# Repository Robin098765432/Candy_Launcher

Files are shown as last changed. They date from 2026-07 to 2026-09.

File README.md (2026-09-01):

# Candy Launcher V1


Hi, this is a finished v1 of the candy launcher, currently only tested on my laptop (HP Victus). 



link to video with more details:
[https://www.youtube.com/watch?v=WshQ-3ue9KE](https://www.youtube.com/watch?v=Oau0cctOxF0)

## Why I Made It
I wanted to build a fun, automated way to launch candy using computer vision, combining hardware (an ESP32 and mechanical parts) with a custom software setup.

## Future updates will bring:
1. improved face tracking, one that also work in dim light
2. improved IK (there seems to be a bug that stops it from following to the full range)
3. improved shot consitency
4. other candy options

## Requirements

### Python

The python script was written with Python 3 and currently only tested on Windows.

Install the required python libraries:

```bash
pip install psutil requests opencv-python numpy
```

### OpenCV

OpenCV already includes:

- `haarcascade_frontalface_default.xml`

You still need to download:

- `haarcascade_mcs_mouth.xml`

and place it in the same folder as the python script.

### ESP32

This project uses an AI-Thinker ESP32-CAM.

Install the ESP32 by Espressif Systems board package through the Arduino IDE Boards Manager.

The following libraries are already included with the board package, so you don't have to install anything extra:

- WiFi
- esp_camera
- esp_http_server

The sketch also expects a `board_config.h` file for the camera pin definitions.

## How to Use It

1. Your laptop must have the physical OMEN Gaming Hub key on the keyboard.
2. Install Python and the required libraries shown above.
3. Download `haarcascade_mcs_mouth.xml` and put it next to the python script.
4. Install the ESP32 board package in the Arduino IDE.
5. Upload the ESP code to the AI-Thinker ESP32 board.
6. Change the Wi-Fi name and password in the ESP sketch.
7. Set the python script to run on Windows startup.
8. Press the OMEN key to enter livestream mode where the python script shows a box around your mouth.

> **Note:** Other esp code is purely for debugging hardware, if something is not working, test the respective section with that code

## CAD
* **CAD Model:** You can check out the design here: [Onshape CAD Document](https://cad.onshape.com/documents/5612db996652adceb7ce30aa/w/0ed39498cd0338a43115c5e1/e/3f8492fab05c535707b619d7)

## Assembly and explanation

> Assembly steps are not set in stone and there are multiple ways to Rome, this is just how i did it. :)
1. mill the pcb out of 1.6mm copper clad, 3d print all the files in the stl folder(make sure the tube and flywheels are printed in tpu)(also make sure that the lid and container are paused at the correct layer and insert the magnets)
2. insert heated inserts in all the holes in the base and solder all components to the pcb
3. mount the servos horns and servos as shown in the picture and bolt them in place


>the 3 servos will be used in sync to tilt the platform towards your mouth
4. insert the balljoints in the circular cutout in the pushrods(should be a press fit), and interlock the side with the fingers with the pushrods with the servo horns and put a bolt through.
> should be a low friction fit

5. mount the pcb with washers as spacers to the platform as shown below. also mount the slide(needs heated inserts first), also mount the motor and the flywheel(all pressfits but can use some glue)


6. install some heated inserts in the container, and mount the cap, slider, servo and servo gear(servo with hot glue), also mount the small dc motor with hot glue in the recess in the cap. and screw the printed weight on the motor shaft


> make sure the servo gear is not installed when first turned on because the servo might jerk to 0 on power on.
> 
> the servo and motor work together to shake the skittles and feed them one at a time
7. connect all the wires according to the diagram
8. snap the tube into the cap and the slide to connect the 2 assemblies and mount on a wall with screws.


9. DONE!!

## Wiring
Candy launcer wiring diagram

## BOM

> Prices are in USD converted from EUR, so they might not be 100% accurate, especially with American websites.

| Item | Qty | Price (USD from EUR, might not be accurate with American websites) | Description | Source / Link |
| :--- | :--- | ---: | :--- | :--- |
| Microcontroller | 1 | 11.55 | AI-Thinker ESP32-CAM | [Link](https://www.amazon.nl/dp/B0D46FHMKQ?ref=ppx_yo2ov_dt_b_fed_asin_title) |
| Host Computer | 1 | 1848.36 | HP Victus Laptop (with OMEN Gaming Hub key) | Owner's Hardware |
| USB Programming Cable | 1 | 10.39 | USB-to-Type-C cable | [Link](https://www.amazon.nl/SUNGUY-USB-compatibel-Android-Auto/dp/B0B28ZCV2Y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) |
| Pcb board | 1, if youre sure you wont mess the milling up;) | 19.36 | single sided | [Link](https://www.amazon.nl/gp/product/B015PCKPXE/ref=ewc_pr_img_1?smid=AQ1IBDB6G2RRD&psc=1) |
| Connecting Wires | as much as you need, can also use some wires you pull out of broken household machines | 0-22.53 | some wires | [Link](https://www.amazon.nl/vaste-gecoat-kleuren-vertind-Fermerry/dp/B09BFFGTLH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) |
| Pla and Tpu  | a roll each | about 44 | for the prints | any online store  |
| power supply | 1 | 18.5 | 5v 6A | [Link](https://www.amazon.nl/dp/B07P8HKFLL?ref=ppx_yo2ov_dt_b_fed_asin_title&th=1) |
| servo | 3 | 25.43 | 15kg | [Link](https://www.amazon.nl/dp/B0DHD4J3B4?ref=ppx_yo2ov_dt_b_fed_asin_title&th=1) |
| bolts  | quite a few | 10.4 | m3 | [Link](https://www.amazon.nl/dp/B0DQ17WWGQ?ref=ppx_yo2ov_dt_b_fed_asin_title&th=1) |
| heated inserts | quite a few | 7.51 | m3 | [Link](https://www.amazon.nl/dp/B0CH32W3W5?ref=ppx_yo2ov_dt_b_fed_asin_title) |
| skittles | depents how much you like skittles | 2.76/pack(150g) | you got to have something to fire | Local store |
| mosfed | 1 | 3.83 | IRL3103 | [Link](https://nl.aliexpress.com/item/1005007481357436.html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) |
| Capacitor | 1 | 3 | 1000uf, >16v | [Link](https://nl.aliexpress.com/item/1005012180336454.html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) |
| magnets, optional | 12 | 5 | 2mm by 4 mm | [Link](https://nl.aliexpress.com/item/1005012419891895.html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) |
| cheap dc motor 5v | 2 | 6 | for shaking and launching | [Link](https://www.amazon.nl/JZK-mini-motor-micro-elektrische-doe-het-zelf-afstandsbediening/dp/B09TRFBSFV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) |
| 9g servo | 1 | 10 | not a lot of torque is needed | [Link](https://www.amazon.nl/Servomotor-Accessoires-Prestatie-Helikopters-Vliegtuigen/dp/B0GXZNC7WV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) |
| rc ball joints  | 3 | 9 | for the platform | [Link](https://www.amazon.nl/dp/B097H25M92?ref=ppx_yo2ov_dt_b_fed_asin_title) |
| resistor 10k ohm | 1 | 0.15 | for the mosfed | [Link](https://www.bitsandparts.nl/weerstand-10k-ohm-1-4w-5pct-p101270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) |
| headers | quite a few |  | to plug everything in | [Link](https://www.amazon.nl/Glarks-Mannelijke-Vrouwelijke-Assortiment-Stapelbare/dp/B09BDX69VX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) |

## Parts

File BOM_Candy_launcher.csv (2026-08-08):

Item | Qty | price(USD from eur, might not be accurate with american websites) | Description | Source / Link
Microcontroller | 1 | 11.55 | AI-Thinker ESP32-CAM | https://www.amazon.nl/dp/B0D46FHMKQ?ref=ppx_yo2ov_dt_b_fed_asin_title
Host Computer | 1 | 1848.36 | HP Victus Laptop (with OMEN Gaming Hub key) | Owner's Hardware
USB Programming Cable | 1 | 10.39 | USB-to-Type-C cable | https://www.amazon.nl/SUNGUY-USB-compatibel-Android-Auto/dp/B0B28ZCV2Y?mcid=637835adbbfa3ec5b925935d5940d08b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
Pcb board | 1, if youre sure you wont mess the milling up;) | 19.36 | single sided | https://www.amazon.nl/gp/product/B015PCKPXE/ref=ewc_pr_img_1?smid=AQ1IBDB6G2RRD&psc=1
Connecting Wires | as much as you need, can also use some wires you pull out of broken household machines | 0-22.53 | some wires | https://www.amazon.nl/vaste-gecoat-kleuren-vertind-Fermerry/dp/B09BFFGTLH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
Pla and Tpu | a roll each | about 44 | for the prints | any online store
drone motor | 2 | 1.13 | for the firing mechanism | https://www.aliexpress.com/p/tesla-landing/index.html?scenario=c_ppc_item_bridge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
power supply | 1 | 18.5 | 5v 6A | https://www.amazon.nl/dp/B07P8HKFLL?ref=ppx_yo2ov_dt_b_fed_asin_title&th=1
servo | 3 | 25.43 | 15kg | https://www.amazon.nl/dp/B0DHD4J3B4?ref=ppx_yo2ov_dt_b_fed_asin_title&th=1
bolts | quite a few | 10.4 | m3 | https://www.amazon.nl/dp/B0DQ17WWGQ?ref=ppx_yo2ov_dt_b_fed_asin_title&th=1
heated inserts | quite a few | 7.51 | m3 | https://www.amazon.nl/dp/B0CH32W3W5?ref=ppx_yo2ov_dt_b_fed_asin_title
skittles | depents how much you like skittles | 2.76/pack(150g) | you got to have something to fire | Local store
mosfed | 1 | 3.83 | IRL3103 | https://nl.aliexpress.com/item/1005007481357436.html
nail | 6 | 5 | 2mm round dia | Local store
magnets, optional | 12 | 5 | 2mm by 4 mm | https://nl.aliexpress.com/item/1005012419891895.html?curPageLogUid=4vGJzhw6EWXI
cheap dc motor 5v | 1 | about 2 | any small one will do | Local store
9g servo | 1 | 10 | not a lot of torque is needed | https://www.amazon.nl/Servomotor-Accessoires-Prestatie-Helikopters-Vliegtuigen/dp/B0GXZNC7WV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

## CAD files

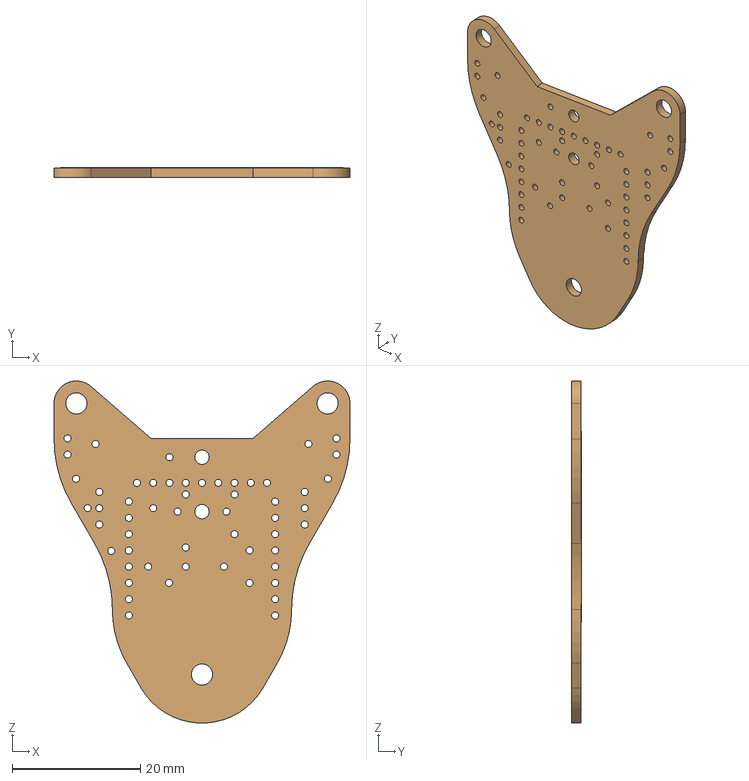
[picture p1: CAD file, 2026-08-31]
Candy launcher - PCB.step
46.2 x 1.60 x 53.4 mm

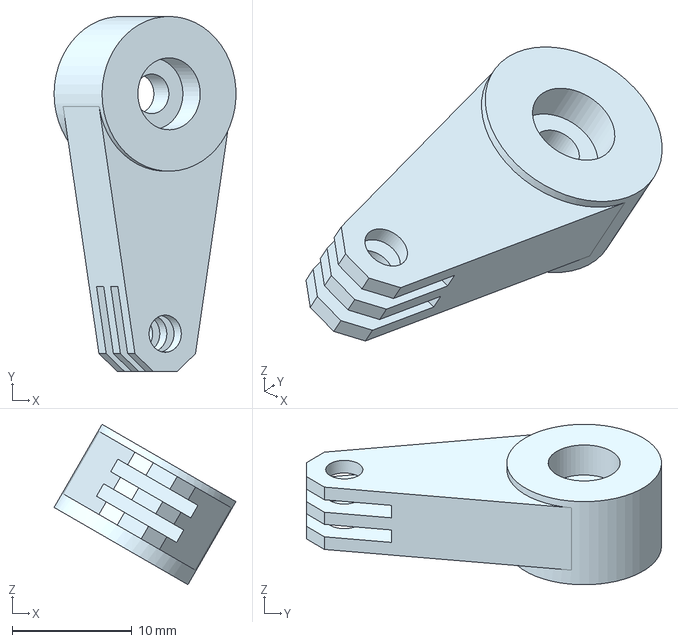
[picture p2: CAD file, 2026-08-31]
Candy launcher step files/Candy launcher - Servo Horn 1.step
15.2 x 29.6 x 13.4 mm

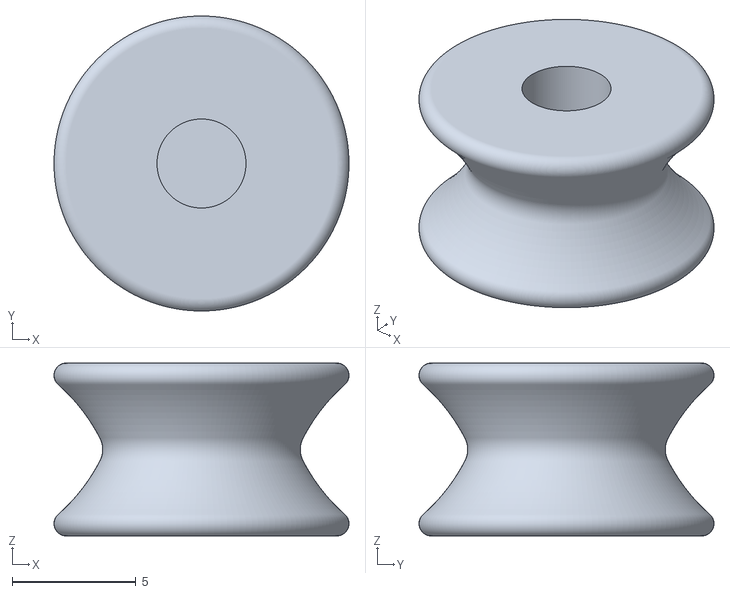
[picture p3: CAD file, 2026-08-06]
Candy launcher Stl files/Candy launcher - Flywheel 2.stl
11.9 x 11.9 x 7.00

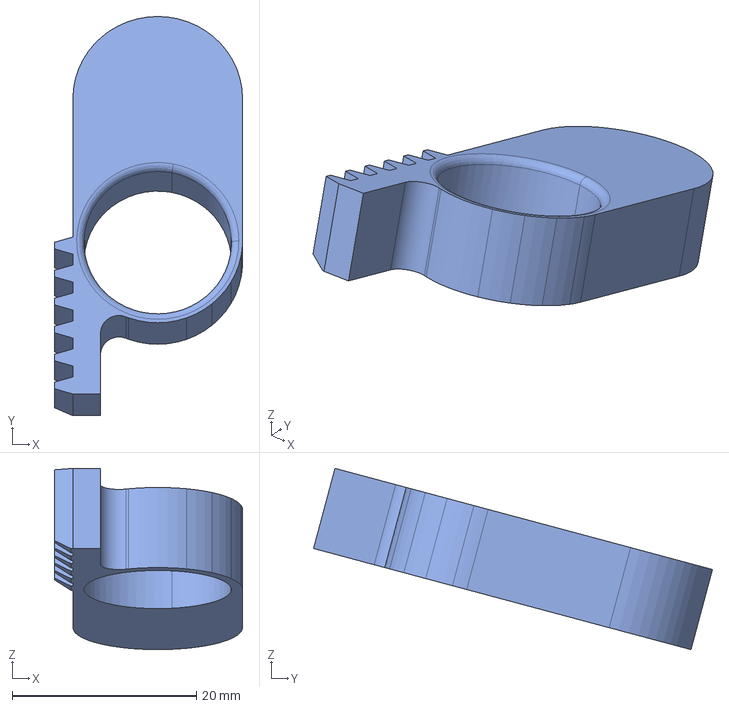
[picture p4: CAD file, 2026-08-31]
Candy launcher step files/Candy launcher - Slider.step
20.4 x 43.3 x 19.7 mm

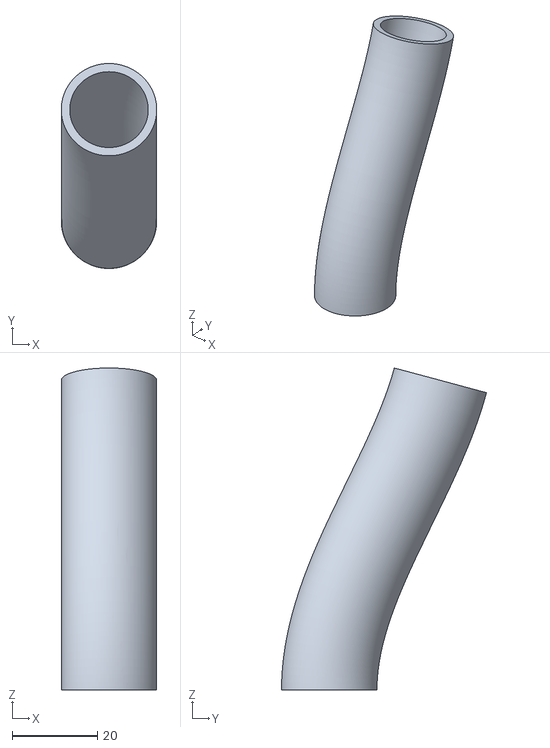
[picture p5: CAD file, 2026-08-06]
Candy launcher Stl files/Candy launcher - tube.stl
22.4 x 48.1 x 75.5

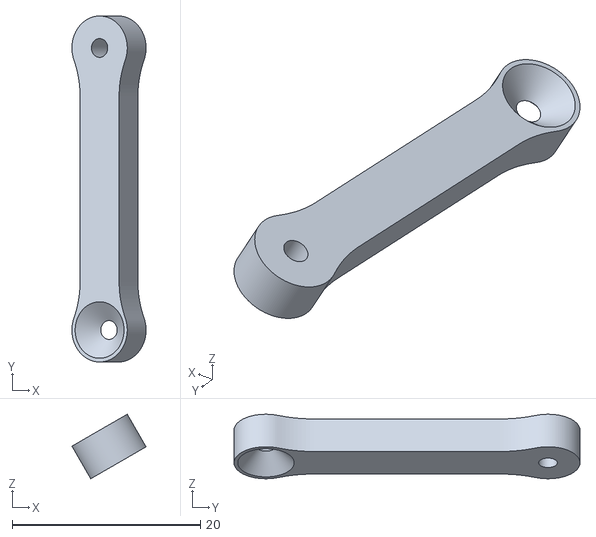
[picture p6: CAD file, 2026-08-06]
Candy launcher Stl files/Candy launcher - Push Rod 3.stl
7.89 x 36.8 x 6.86

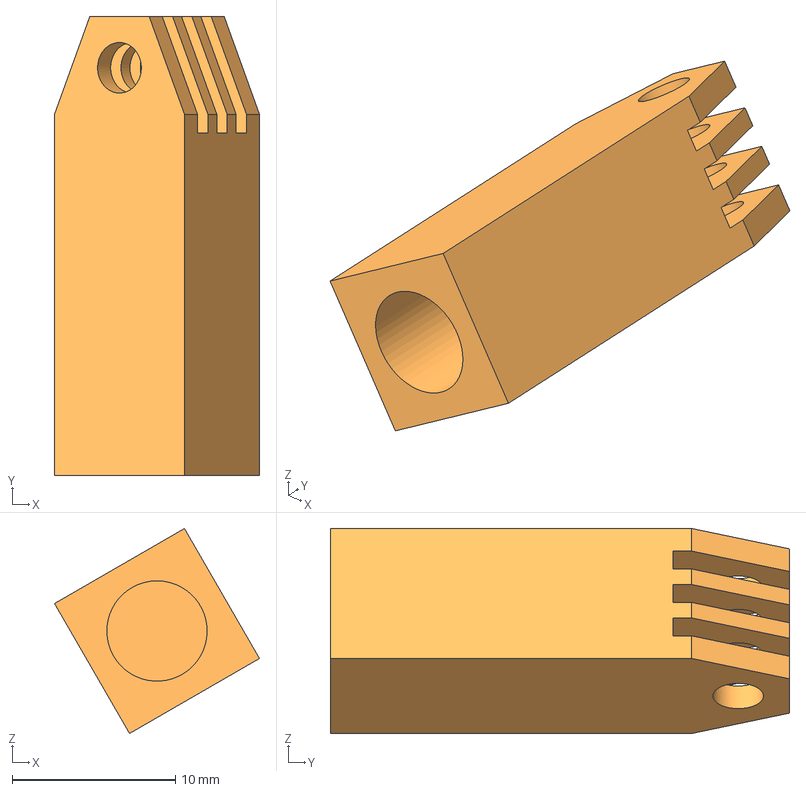
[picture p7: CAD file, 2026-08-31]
Candy launcher step files/Candy launcher - Servo rod 3.step
12.6 x 28.2 x 12.6 mm

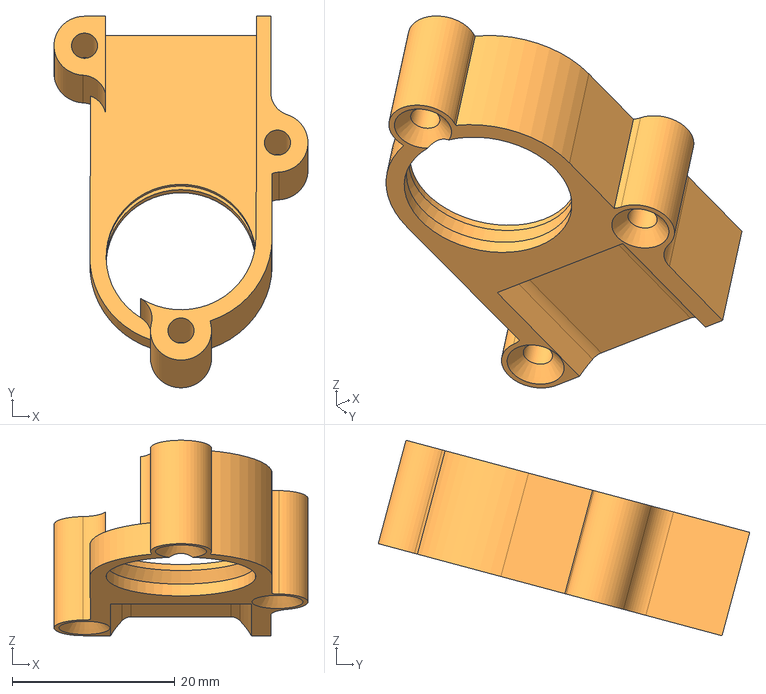
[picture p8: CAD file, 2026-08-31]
Candy launcher step files/Candy launcher - Cap.step
31.2 x 45.6 x 24.0 mm

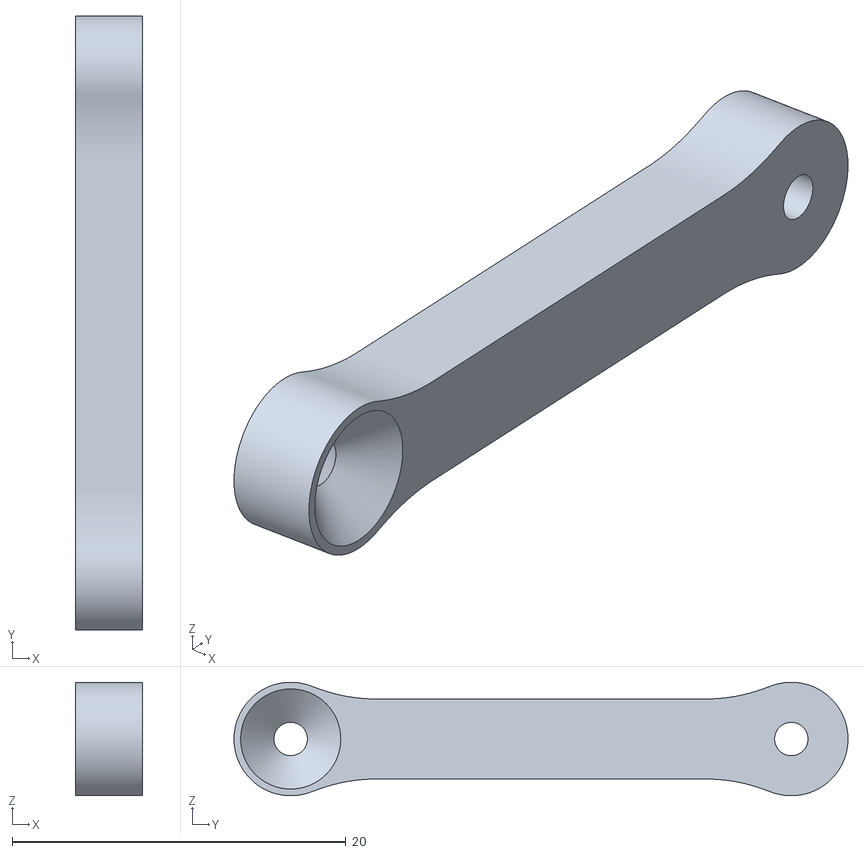
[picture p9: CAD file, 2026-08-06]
Candy launcher Stl files/Candy launcher - Push Rod 2.stl
4.00 x 36.8 x 6.80

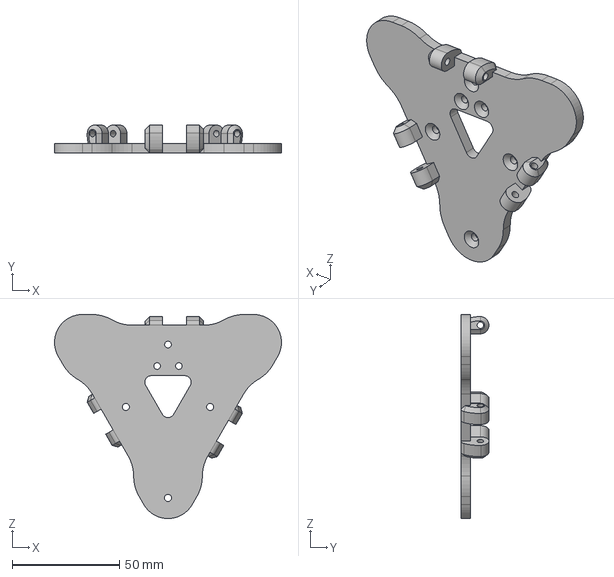
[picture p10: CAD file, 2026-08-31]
Candy launcher step files/Candy launcher - Platform.step
105.7 x 13.0 x 95.0 mm

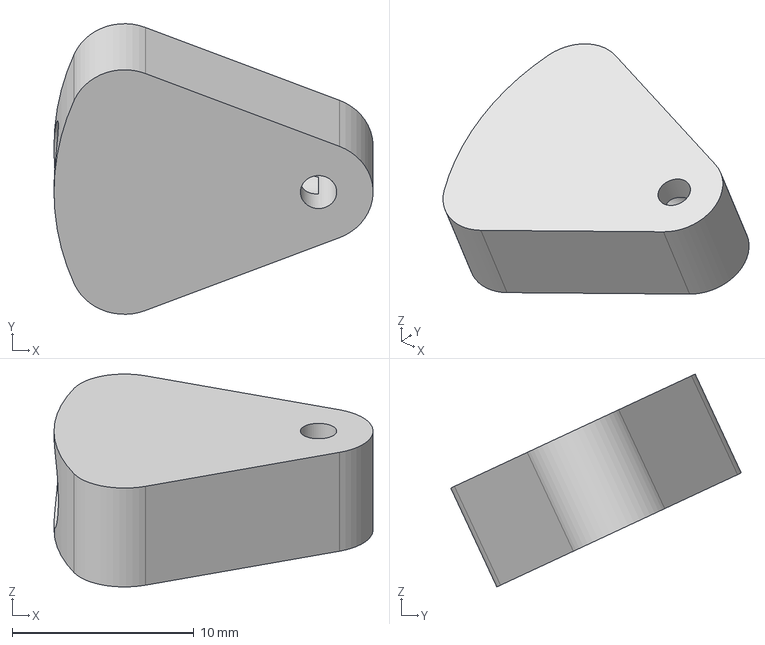
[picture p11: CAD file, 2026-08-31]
Candy launcher step files/Candy launcher - Weight.step
17.5 x 16.0 x 11.7 mm

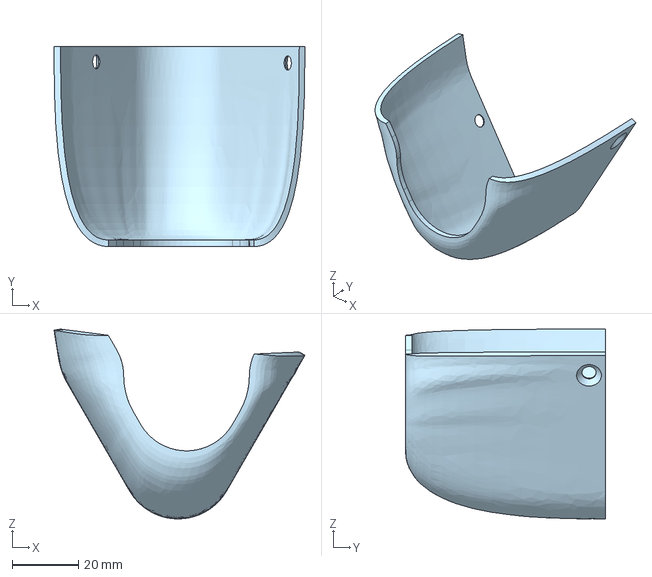
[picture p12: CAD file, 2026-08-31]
Candy launcher step files/Candy launcher - Cover 3.step
75.9 x 60.5 x 57.4 mm

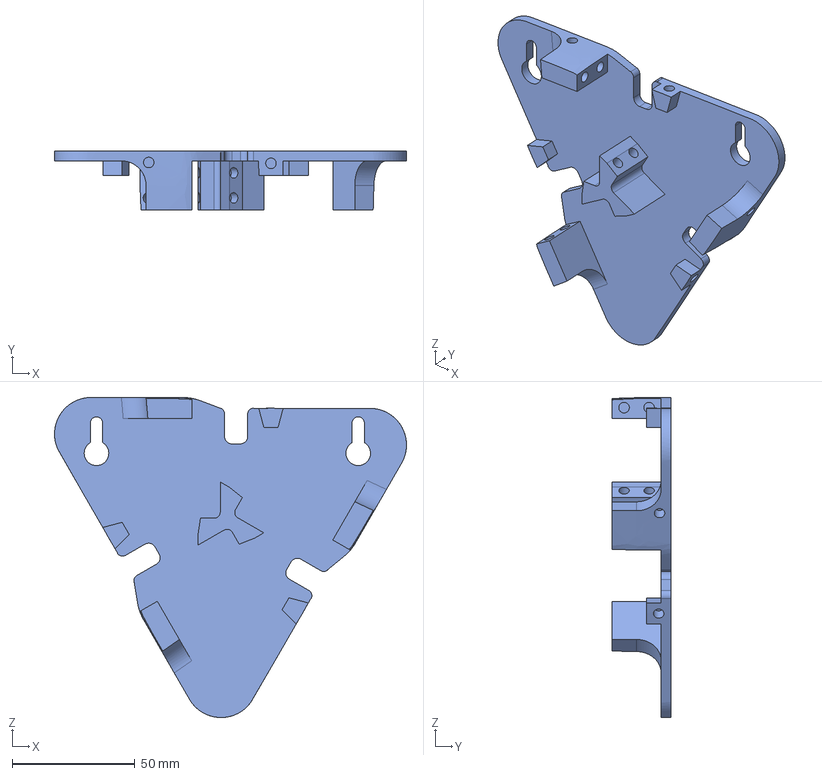
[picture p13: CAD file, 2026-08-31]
Candy launcher step files/Candy launcher - Base.step
143.4 x 24.0 x 130.4 mm

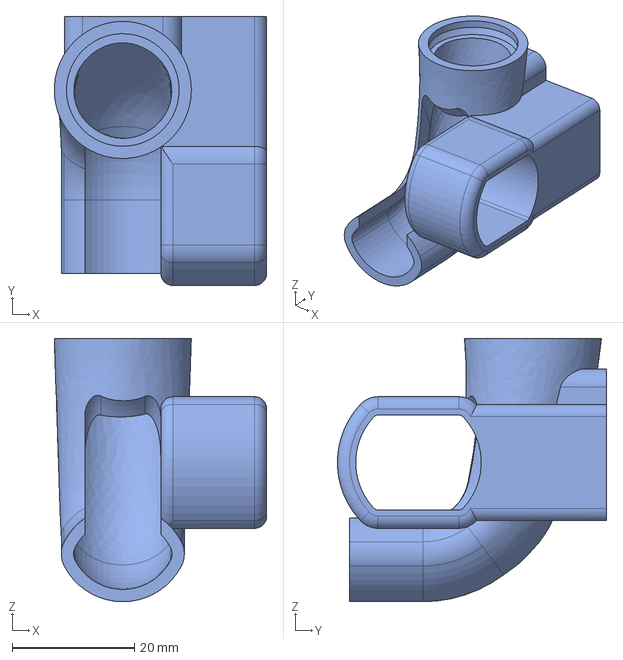
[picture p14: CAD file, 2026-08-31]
Candy launcher step files/Candy launcher - Slide.step
34.7 x 43.9 x 43.0 mm

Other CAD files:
Candy launcher Stl files/Candy launcher - Push Rod 1.stl
Candy launcher Stl files/Candy launcher - Flywheel 1.stl
Candy launcher step files/Candy launcher - Servo rod 1.step
Candy launcher Stl files/Candy launcher - Base.stl
Candy launcher Stl files/Candy launcher - Cap.stl
Candy launcher Stl files/Candy launcher - Container.stl
Candy launcher Stl files/Candy launcher - Cover 1.stl
Candy launcher Stl files/Candy launcher - Cover 2.stl
Candy launcher Stl files/Candy launcher - Cover 3.stl
Candy launcher Stl files/Candy launcher - Flex tube.stl
Candy launcher Stl files/Candy launcher - Lid.stl
Candy launcher Stl files/Candy launcher - Part 24.stl
Candy launcher Stl files/Candy launcher - Part 25.stl
Candy launcher Stl files/Candy launcher - Platform.stl
Candy launcher Stl files/Candy launcher - Servo Horn 1.stl
Candy launcher Stl files/Candy launcher - Servo Horn 2.stl
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

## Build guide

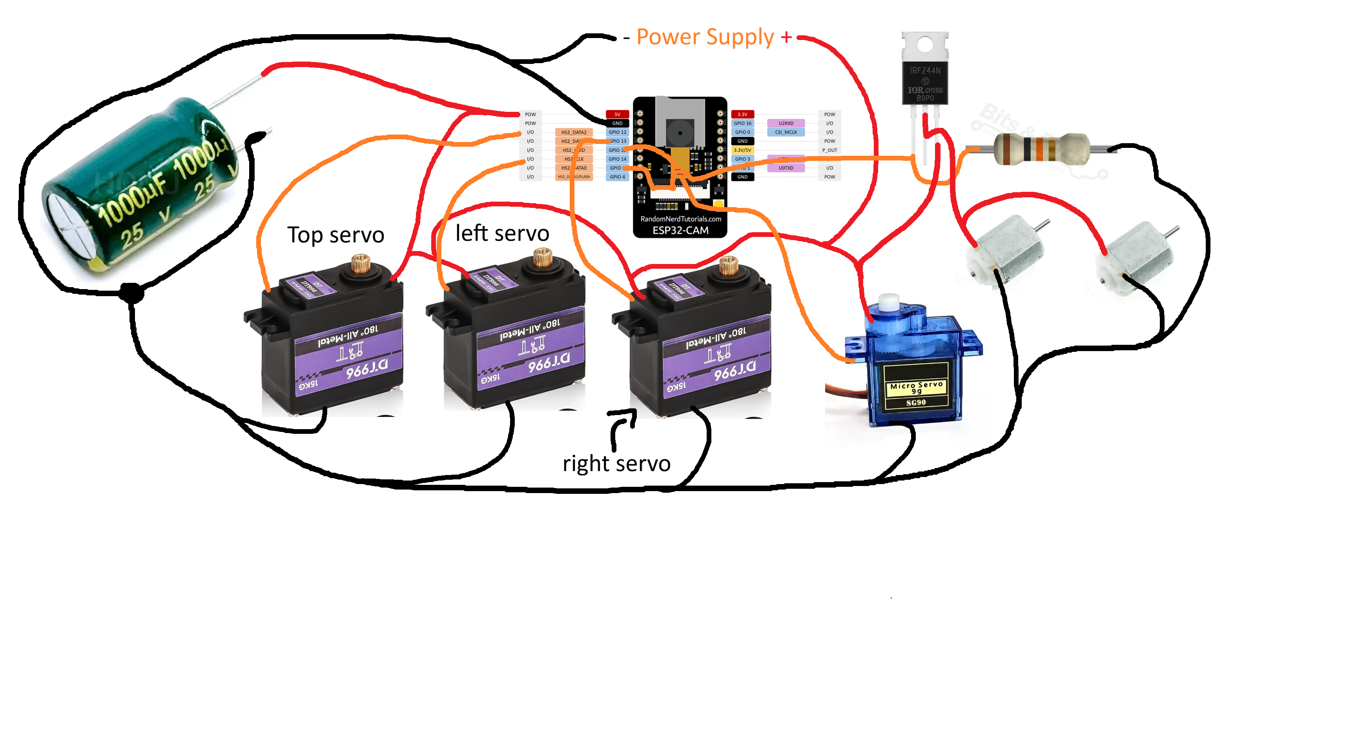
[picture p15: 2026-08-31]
Candy launcer wiring diagram.png

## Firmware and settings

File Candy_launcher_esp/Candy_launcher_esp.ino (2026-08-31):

#include "esp_camera.h"
#include <WiFi.h>
#include "esp_http_server.h"
#include <ESP32Servo.h>
#include "board_config.h"

const char* ssid = "Jojanneke en Linda 2";
const char* password = "C00kiemonster!!";

Servo servo1;
Servo servo2;
Servo servo3;
Servo servo4;

const int SERVO1_PIN = 12;
const int SERVO2_PIN = 13;
const int SERVO3_PIN = 14;
const int SERVO4_PIN = 15;

const int IO2_PIN = 2;
const int PWM_VALUE = 255;

float curr_servo1_angle = 165;
float curr_servo2_angle = 165;
float curr_servo3_angle = 165;

float target_servo1_angle = 165;
float target_servo2_angle = 165;
float target_servo3_angle = 165;

bool servo_update_pending = false;

IPAddress local_IP(192, 168, 0, 120);
IPAddress gateway(192, 168, 0, 1);
IPAddress subnet(255, 255, 0, 0);

httpd_handle_t camera_httpd = NULL;


bool fire_requested = false;


static esp_err_t capture_handler(httpd_req_t *req) {
  camera_fb_t *fb = esp_camera_fb_get();

  if (!fb) {httpd_resp_send_500(req);
    return ESP_FAIL;
  }

  httpd_resp_set_type(req, "image/jpeg");
  httpd_resp_set_hdr(req, "Cache-Control", "no-store");
  httpd_resp_set_hdr(req, "Connection", "close");

  esp_err_t res = httpd_resp_send(req, (const char *)fb->buf, fb->len);

  esp_camera_fb_return(fb);

  return res;
}


bool readCommand(httpd_req_t *req, char *buffer, size_t buffer_size) {
  if (req->content_len <= 0) {
    return false;
  }

  if (req->content_len >= buffer_size) {
    return false;
  }

  int ret = httpd_req_recv(req, buffer, buffer_size - 1);

  if (ret <= 0) {
    return false;
  }

  buffer[ret] = '\0';

  return true;
}



static esp_err_t command_handler(httpd_req_t *req) {
  char buffer[128];

  if (!readCommand(req, buffer, sizeof(buffer))) {
    httpd_resp_send(req, "INVALID_COMMAND", HTTPD_RESP_USE_STRLEN);
    return ESP_OK;
  }

  String command = String(buffer);
  command.trim();


  if (command == "FIRE") {
    if (fire_requested) {
      httpd_resp_send(req, "FIRE_BUSY", HTTPD_RESP_USE_STRLEN);
      return ESP_OK;
    }

    fire_requested = true;
    httpd_resp_send(req, "FIRE_OK", HTTPD_RESP_USE_STRLEN);
    return ESP_OK;
  }


  if (command == "FLASH_OFF") {

    digitalWrite(LED_GPIO_NUM, LOW);

    httpd_resp_send(req, "LED_OFF", HTTPD_RESP_USE_STRLEN);

    return ESP_OK;
  }


  if (command == "FLASH_ON") {

    digitalWrite(LED_GPIO_NUM, HIGH);

    httpd_resp_send(req, "LED_ON", HTTPD_RESP_USE_STRLEN);

    return ESP_OK;
  }



  if (command.startsWith("SET_SERVO_ANGLES")) {

    int first_space = command.indexOf(' ');
    int second_space = command.indexOf(' ', first_space + 1);
    int third_space = command.indexOf(' ', second_space + 1);

    if (first_space == -1 || second_space == -1 || third_space == -1) {
      httpd_resp_send( req, "INVALID_SERVO_COMMAND", HTTPD_RESP_USE_STRLEN);

      return ESP_OK;
    }

    float angle1 = command.substring( first_space + 1, second_space).toFloat();

    float angle2 = command.substring( second_space + 1, third_space).toFloat();

    float angle3 = command.substring( third_space + 1).toFloat();

    if (angle1 < 90 || angle1 > 165 || angle2 < 90 || angle2 > 165 || angle3 < 90 || angle3 > 165) {
      httpd_resp_send(req, "INVALID_SERVO_ANGLE", HTTPD_RESP_USE_STRLEN);

      return ESP_OK;
    }

    target_servo1_angle = angle1;
    target_servo2_angle = angle2;
    target_servo3_angle = angle3;

    servo_update_pending = true;

    httpd_resp_send( req, "SERVO_ANGLES_SET", HTTPD_RESP_USE_STRLEN);

    return ESP_OK;
  }


  httpd_resp_send( req, "UNKNOWN_COMMAND", HTTPD_RESP_USE_STRLEN);

  return ESP_OK;
}

void startCameraServer() {
  httpd_config_t config = HTTPD_DEFAULT_CONFIG();

  config.server_port = 80;
  config.max_open_sockets = 4;
  config.lru_purge_enable = true;

  httpd_uri_t capture_uri = {.uri = "/capture", .method = HTTP_GET, .handler = capture_handler, .user_ctx = NULL};

  httpd_uri_t command_uri = {.uri = "/send_command", .method = HTTP_POST, .handler = command_handler, .user_ctx = NULL};

  if (httpd_start(&camera_httpd, &config) == ESP_OK) {

    httpd_register_uri_handler(camera_httpd, &capture_uri);

    httpd_register_uri_handler( camera_httpd, &command_uri);
  }
}


void processServoMovement() {

  if (!servo_update_pending) {
    return;
  }

  servo_update_pending = false;

  float angle1 = target_servo1_angle;
  float angle2 = target_servo2_angle;
  float angle3 = target_servo3_angle;

  servo1.write(angle1);

  servo2.write(angle2);

  servo3.write(angle3);

  curr_servo1_angle = angle1;
  curr_servo2_angle = angle2;
  curr_servo3_angle = angle3;
}


void processFire() {
  if (!fire_requested) {
    return;
  }

  ledcWrite(IO2_PIN, 155);
  delay(1000);
  servo4.write(180);
  delay(1500);
  servo4.write(0);
  ledcWrite(IO2_PIN, 0);

  fire_requested = false;
}

bool initializeCamera() {

  camera_config_t config = {};

  config.ledc_channel = LEDC_CHANNEL_0;
  config.ledc_timer = LEDC_TIMER_0;

  config.pin_d0 = Y2_GPIO_NUM;
  config.pin_d1 = Y3_GPIO_NUM;
  config.pin_d2 = Y4_GPIO_NUM;
  config.pin_d3 = Y5_GPIO_NUM;
  config.pin_d4 = Y6_GPIO_NUM;
  config.pin_d5 = Y7_GPIO_NUM;
  config.pin_d6 = Y8_GPIO_NUM;
  config.pin_d7 = Y9_GPIO_NUM;

  config.pin_xclk = XCLK_GPIO_NUM;
  config.pin_pclk = PCLK_GPIO_NUM;
  config.pin_vsync = VSYNC_GPIO_NUM;
  config.pin_href = HREF_GPIO_NUM;

  config.pin_sscb_sda = SIOD_GPIO_NUM;
  config.pin_sscb_scl = SIOC_GPIO_NUM;

  config.pin_pwdn = PWDN_GPIO_NUM;
  config.pin_reset = RESET_GPIO_NUM;

  config.xclk_freq_hz = 20000000;

  config.pixel_format = PIXFORMAT_JPEG;

  config.frame_size = FRAMESIZE_VGA;
  config.jpeg_quality = 12;

  if (psramFound()) {
    config.fb_count = 2;
    config.fb_location = CAMERA_FB_IN_PSRAM;
    config.grab_mode = CAMERA_GRAB_LATEST;
  }
  else {
    config.fb_count = 1;
  }

  esp_err_t err = esp_camera_init(&config);

  if (err != ESP_OK) {
    return false;
  }

  return true;
}

void setup() {

  Serial.begin(115200);

  delay(500);

  pinMode(LED_GPIO_NUM, OUTPUT);
  digitalWrite(LED_GPIO_NUM, LOW);

  ledcAttach(IO2_PIN, 5000, 8);
  ledcWrite(IO2_PIN, 0);

  ESP32PWM::allocateTimer(1);
  ESP32PWM::allocateTimer(2);
  ESP32PWM::allocateTimer(3);

  servo1.setPeriodHertz(50);
  servo2.setPeriodHertz(50);
  servo3.setPeriodHertz(50);
  servo4.setPeriodHertz(50);

  servo1.attach(SERVO1_PIN, 1000, 2000);
  servo2.attach(SERVO2_PIN, 1000, 2000);
  servo3.attach(SERVO3_PIN, 1000, 2000);
  servo4.attach(SERVO4_PIN, 500, 2500);

  servo1.write(curr_servo1_angle);
  servo2.write(curr_servo2_angle);
  servo3.write(curr_servo3_angle);
  servo4.write(0);

  delay(300);

  if (!initializeCamera()) {
    ESP.restart();
  }

  if (!WiFi.config(local_IP, gateway, subnet)) {
    Serial.println("WiFi config failed");
  }

  WiFi.mode(WIFI_STA);
  WiFi.begin(ssid, password);

  while (WiFi.status() != WL_CONNECTED) {
    delay(500);
  }

  Serial.println("WiFi connected");
  Serial.println(WiFi.localIP());

  startCameraServer();
}

void loop() {

  processServoMovement();

  processFire();

  if (WiFi.status() != WL_CONNECTED) {
    WiFi.reconnect();
  }

  delay(5);
}

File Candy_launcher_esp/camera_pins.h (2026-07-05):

#ifndef CAMERA_PINS_H
#define CAMERA_PINS_H

#define PWDN_GPIO_NUM  32
#define RESET_GPIO_NUM -1
#define XCLK_GPIO_NUM  0
#define SIOD_GPIO_NUM  26
#define SIOC_GPIO_NUM  27

#define Y9_GPIO_NUM    35
#define Y8_GPIO_NUM    34
#define Y7_GPIO_NUM    39
#define Y6_GPIO_NUM    36
#define Y5_GPIO_NUM    21
#define Y4_GPIO_NUM    19
#define Y3_GPIO_NUM    18
#define Y2_GPIO_NUM     5
#define VSYNC_GPIO_NUM 25
#define HREF_GPIO_NUM  23
#define PCLK_GPIO_NUM  22

// 4 for flash led or 33 for normal led
#define LED_GPIO_NUM    4

#endif

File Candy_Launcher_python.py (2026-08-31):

import psutil
import time
import requests
import cv2
import numpy as np


seen = set()

Servo1 = [25.82, -64.80, -17.28]
Servo2 = [2.06, -64.80, 31.00]
Servo3 = [-27.88, -64.80, -13.72]

Plane_normal = [0.0, 1.0, 0.0]

Distance = 1200
focal_length = 543

image_center_x = 320
image_center_y = 240

SCREEN_CENTER_X = 320

ESP32_IP = "192.168.0.120"

CAPTURE_URL = f"http://{ESP32_IP}/capture"
COMMAND_URL = f"http://{ESP32_IP}/send_command"

gain = 0.2

AIM_TOLERANCE_X = 50
AIM_TOLERANCE_Y = 50

STABLE_FRAMES_REQUIRED = 5

SERVO_UPDATE_INTERVAL = 0.2
SERVO_CHANGE_THRESHOLD = 0.5

last_servo_angles = None
last_servo_time = 0
min_servo_angle = 90
max_servo_angle = 165

stable_frames = 0
fire_sent = False

face_classifier = cv2.CascadeClassifier(cv2.data.haarcascades + "haarcascade_frontalface_default.xml")

mouth_classifier = cv2.CascadeClassifier("haarcascade_mcs_mouth.xml")


def IK(pitch_deg, roll_deg):

    platform_distance = 50.0

    platform_y = Servo1[1] + platform_distance

    pitch = np.radians(pitch_deg)
    roll = np.radians(roll_deg)

    P1_reference = np.array([Servo1[0], platform_y, Servo1[2]], dtype=float)

    P2_reference = np.array([Servo2[0], platform_y, Servo2[2]], dtype=float)

    P3_reference = np.array([Servo3[0], platform_y, Servo3[2]], dtype=float)

    platform_center = (P1_reference + P2_reference + P3_reference) / 3.0

    Rx = np.array([[1, 0, 0], [0, np.cos(pitch), -np.sin(pitch)], [0, np.sin(pitch), np.cos(pitch)]])

    Rz = np.array([[np.cos(roll), -np.sin(roll), 0], [np.sin(roll), np.cos(roll), 0], [0, 0, 1]])

    R = Rx @ Rz

    P1 = (platform_center + R @ (P1_reference - platform_center))

    P2 = (platform_center + R @ (P2_reference - platform_center))

    P3 = (platform_center + R @ (P3_reference - platform_center))

    horn_length = 20
    rod_length = 30
    servo_reference = 165

    distance_1 = np.linalg.norm(P1 - Servo1)

    cos_1 = (rod_length ** 2 + distance_1 ** 2 - horn_length ** 2) / (2 * rod_length * distance_1)

    cos_1 = np.clip(cos_1, -1.0, 1.0)

    servo_1_angle = np.clip(servo_reference - np.degrees(np.arccos(cos_1)), min_servo_angle, max_servo_angle)

    distance_2 = np.linalg.norm(P2 - Servo2)

    cos_2 = (rod_length ** 2 + distance_2 ** 2 - horn_length ** 2) / (2 * rod_length * distance_2)

    cos_2 = np.clip(cos_2, -1.0, 1.0)

    servo_2_angle = np.clip(servo_reference - np.degrees(np.arccos(cos_2)), min_servo_angle, max_servo_angle)

    distance_3 = np.linalg.norm(P3 - Servo3)

    cos_3 = (rod_length ** 2 + distance_3 ** 2 - horn_length ** 2) / (2 * rod_length * distance_3)

    cos_3 = np.clip(cos_3, -1.0, 1.0)

    servo_3_angle = np.clip(servo_reference - np.degrees(np.arccos(cos_3)), min_servo_angle, max_servo_angle)

    print(f"Servo angles: "f"{servo_1_angle:.2f}, "f"{servo_2_angle:.2f}, "f"{servo_3_angle:.2f}")

    return (servo_1_angle, servo_2_angle, servo_3_angle)


def sent_command(command):

    try:

        response = requests.post(COMMAND_URL, data=command, timeout=4)

        result = response.text.strip()

        print(f"Sent command: [{command}] " f"-> ESP32 Replied: [{result}]")

        return result

    except requests.exceptions.Timeout:
        print("ESP32 command timed out")
        return None

    except requests.exceptions.RequestException as e:
        print(f"ESP32 command error: {e}")
        return None

def capture_image():

    try:

        response = requests.get(CAPTURE_URL, timeout=3, headers={ "Connection": "close"})

        if response.status_code == 200:

            frame = cv2.imdecode(np.frombuffer(response.content, dtype=np.uint8), cv2.IMREAD_COLOR)

            return frame

        print(f"Server error fetching image. "f"Status code: {response.status_code}")

        return None

    except requests.exceptions.Timeout:

        print("Camera request timed out")

        return None

    except requests.exceptions.RequestException as e:

        print(f"Camera request error: {e}")

        return None


while True:

    for p in psutil.process_iter(['pid', 'name']):

        name = (p.info['name'] or "").lower()

        pid = p.info['pid']

        if "hp.omen.omencommandcenter" in name:

            if pid not in seen:

                seen.add(pid)

                try:
                    psutil.Process(pid).terminate()
                except:
                    pass

                stable_frames = 0
                fire_sent = False
                last_servo_angles = None
                last_servo_time = 0

                while True:

                    time.sleep(0.05)

                    frame = cv2.flip(capture_image(), -1)

                    if frame is None:
                        continue

                    height, width = frame.shape[:2]

                    image_center_x = width // 2
                    image_center_y = height // 2

                    SCREEN_CENTER_X = image_center_x

                    gray_image = cv2.cvtColor(frame, cv2.COLOR_BGR2GRAY)

                    display = frame.copy()


                    face = face_classifier.detectMultiScale(gray_image, scaleFactor=1.1, minNeighbors=5, minSize=(40, 40))

                    if len(face) > 0:

                        closest_face = min(face, key=lambda b: abs((b[0] + b[2] // 2) - SCREEN_CENTER_X))

                        face_x, face_y, face_w, face_h = (closest_face)

                        cv2.rectangle(display, (face_x, face_y), (face_x + face_w, face_y + face_h), (255, 0, 0), 2)

                        face_cropped_gray = gray_image[face_y:face_y + face_h, face_x:face_x + face_w]

                        lower_face = face_cropped_gray[face_h // 2:, :]

                        mouth = mouth_classifier.detectMultiScale(lower_face, scaleFactor=1.1, minNeighbors=15,  minSize=(20, 20))

                        if len(mouth) > 0:

                            mouth_box = max(mouth, key=lambda b: b[1])

                            mouth_x, mouth_y, mouth_w, mouth_h = (mouth_box)

                            mouth_y += face_h // 2

                            target_x = (face_x + mouth_x + mouth_w // 2)

                            target_y = ( face_y + mouth_y + mouth_h // 2)

                            print(f"Mouth detected at "f"({target_x}, {target_y})")

                            cv2.rectangle(display, (face_x + mouth_x, face_y + mouth_y), (face_x + mouth_x + mouth_w, face_y + mouth_y + mouth_h), (0, 255, 0), 2)

                            cv2.circle(display,(target_x, target_y), 4, (255, 255, 255), -1)

                            error_x = (target_x - image_center_x)

                            error_y = (target_y - image_center_y)

                            pitch = gain * error_y
                            roll = gain * error_x

                            IK_angles = IK(pitch, roll)

                            angles_valid = all(min_servo_angle <= angle <= max_servo_angle for angle in IK_angles)
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

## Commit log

2026-07-05 Add face and mouth detection functionality to ESP32 trigger process
2026-07-05 all the arduino code
    [partitions.csv]
2026-07-05 hopefully fixed the errors vscode was giving me
    [Candy_launcher_esp.ino]
2026-07-26 Create README for candy launcher prototype
    Added initial README for candy launcher prototype with setup instructions and CAD link.
2026-08-06 Revise README with usage and BOM details
    Updated README to include detailed usage instructions, a CAD section, and a Bill of Materials (BOM). Improved formatting and added notes on the project's current status.
2026-08-06 Update WiFi credentials and add servo configuration parameters
2026-08-06 Expand README with project requirements and setup
    Added requirements section detailing Python, OpenCV, and ESP32 setup instructions.
2026-08-07 Revise BOM with prices and additional items
    Updated the BOM section to include pricing and additional items.
2026-08-07 Enhance README with assembly and wiring details
    Added assembly steps and wiring instructions to the README.
2026-08-07 Fix typos and enhance assembly explanation in README
    Corrected typos and improved clarity in assembly instructions.
2026-08-07 Refactor BOM table and add new components
    Updated the BOM table format for better readability and added new items.
2026-08-08 Refactor camera reset message and add servo control example
    [Candy_launcher_esp.ino, Servo_test_esp.ino]
2026-08-11 Remove Servo test example code
2026-08-14 Update README with new images and assembly steps
    Added an additional image and updated the instructions for assembly.
2026-08-14 Refactor face detection messages for clarity; update WiFi credentials; add servo control example
2026-08-14 Reset WiFi credentials to default values in Candy_launcher_esp.ino
    [Candy_launcher_esp.ino]
2026-08-21 Refactor servo control logic in Launch_test_esp.ino; replace digitalWrite with analogWrite for PWM control
    [Launch_test_esp.ino]
2026-08-23 Implement inverse kinematics function for servo angle calculations; update servo control logic in ESP32 code
2026-08-30 Refactor ESP32 code for improved command handling and servo control; enhance camera capture and error handling because the esp was failing to connect after servo movement
    [Candy_Launcher_python.py, Candy_launcher_esp.ino]
2026-08-31 Adjust servo angle limits and refine fire command handling; improve timing and response logic
2026-08-31 Replace wiring image with candy launcher diagram
    Updated wiring section with a new image for the candy launcher diagram.
2026-08-31 Reset WiFi credentials to default values
    [Candy_launcher_esp.ino]
2026-08-31 Revise README for completed v1 and assembly details
    Updated README to reflect the completion of version 1 of the candy launcher, added future update plans, and improved assembly instructions.
2026-09-01 Update WiFi credentials and adjust servo4 attachment parameters
2026-10-22 Rename Candy launcher Stl files/Candy launcher - Base.stl to CAD/Candy launcher Stl files/Candy launcher - Base.stl
2026-10-22 Rename CAD/Candy launcher Stl files/Candy launcher - Base.stl to Candy launcher Stl files/Candy launcher - Base.stl
2026-10-31 Remove outdated wiring diagram and add new version
2026-10-31 Update wiring diagram with new version
2026-11-01 Rename Candy_launcher wiring diagram.png to Candy_launcher wiring diagram NEW.png
2026-11-01 Replace old wiring diagram with updated version
2026-11-01 Add wiring diagram image to README
    Added a new wiring diagram image to the README.
2026-11-01 Replace wiring image with new diagram
    Updated wiring diagram image in README.
